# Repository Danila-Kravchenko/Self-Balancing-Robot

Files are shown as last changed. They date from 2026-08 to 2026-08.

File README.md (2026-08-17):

# Балансирующий робот

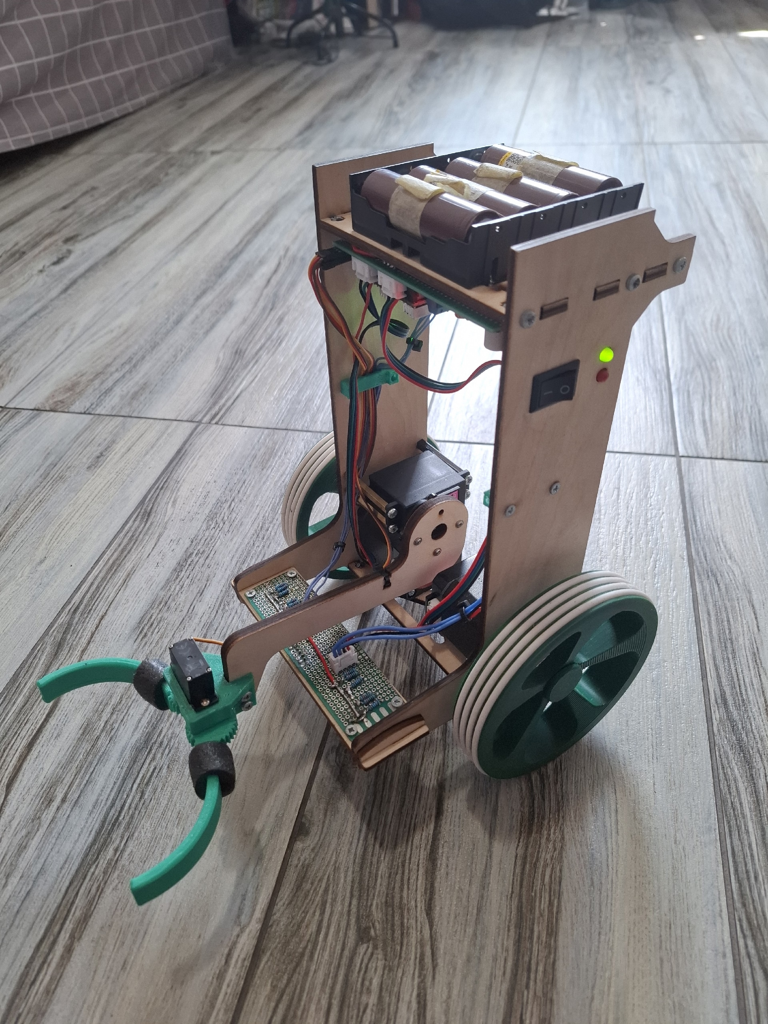
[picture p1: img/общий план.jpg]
общий план


Робот предназначен для выступления на соревнованиях РобоФинист в категории «Гонки балансирующих роботов».
Задача робота — проехать вытянутый S-образный полигон, преодолевая препятствия (горку и кирпич), а также захватить муфту на первом прямолинейном участке.
Победитель определяется по наибольшему числу набранных баллов или по более быстрой попытке.
Подробнее с регламентом можно ознакомиться по [ссылке](https://cdn.robofinist.ru/files/324540/filename/%D0%A0%D0%B5%D0%B3%D0%BB%D0%B0%D0%BC%D0%B5%D0%BD%D1%82%20%D0%93%D0%BE%D0%BD%D0%BA%D0%B8%20%D0%B1%D0%B0%D0%BB%D0%B0%D0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).

---

## Аппаратная архитектура

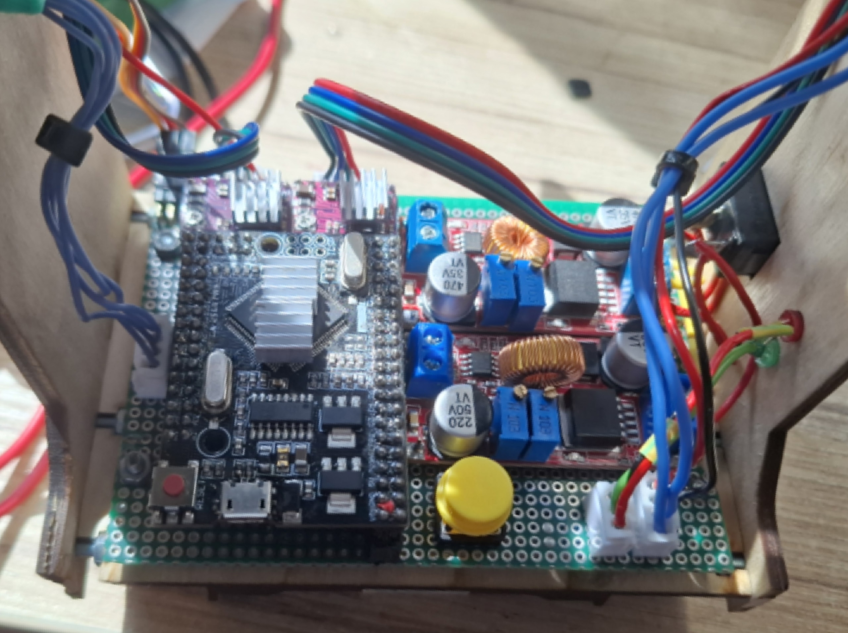
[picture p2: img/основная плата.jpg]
основная плата


### Контроллер
* Arduino Mega 2560 Pro.

### Датчики и сенсоры
* **Удержание угла:** инерциальный модуль BNO-055.
* **Интерфейс:** тактовая кнопка для калибровки систем и старта алгоритма.
* **Следование по линии:** 4 оптопары TCRT5000.
* **Обнаружение препятствий:** лазерный дальномер VL53L1X.

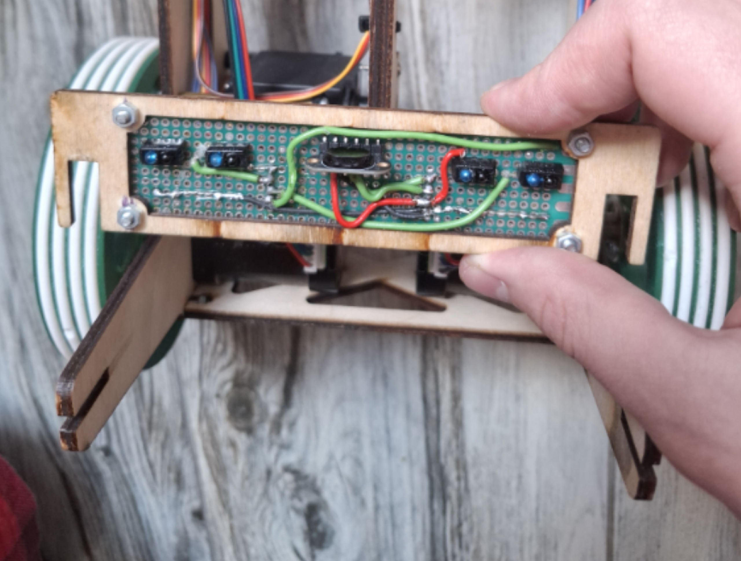
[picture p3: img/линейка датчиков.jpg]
линейка датчиков


### Исполнительные устройства
* **Моторы:** 2 шаговых двигателя Nema 17 17HS8401.
* **Драйверы управления двигателями:** DRV8825.
* **Манипулятор:**
    * сервопривод подъёма стрелы — MG996R;
    * сервопривод клешней — Kingmax KM0940MD.

### Система питания
* **Источник питания:** сборка 4S1P из Li-ion аккумуляторов 18650, 3000 мА·ч.
* **Распределение питания:**
    * шаговые двигатели — 16 В (напрямую от батареи);
    * сервоприводы — 7 В от стабилизатора XL4015;
    * контроллер — 6 В от второго стабилизатора XL4015 на пин Vin;
    * сенсоры — 5 В от пина 5V контроллера.

---

## Конструкция и механика

* **Рама:** лазерная резка из фанеры 4 мм. Сборка выполнена по системе «шип-паз» с механической фиксацией винтами.
* **Фронтальный модуль сенсоров:** дальномер и линейка датчиков линии объединены на единой съёмной текстолитовой плате в передней части робота.
* **Кабель-менеджмент:** по бортам робота установлены напечатанные на 3D-принтере фиксирующие гребёнки для укладки проводов.
* **Движители:** кастомные колёса (3D-печать). В пазы колёс установлены силиконовые шнуры диаметром 3 мм, склеенные в кольца суперклеем.

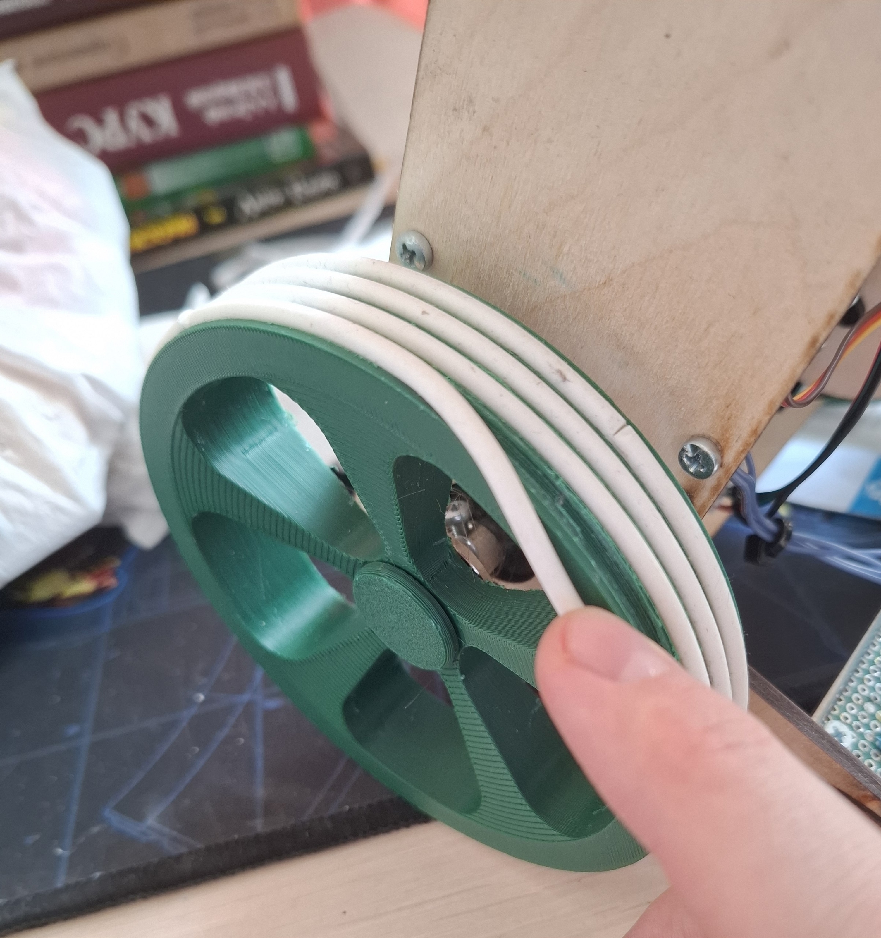
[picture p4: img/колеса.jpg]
колеса


* **Рабочий орган:** клешни манипулятора спроектированы под геометрию муфты и распечатаны на 3D-принтере.

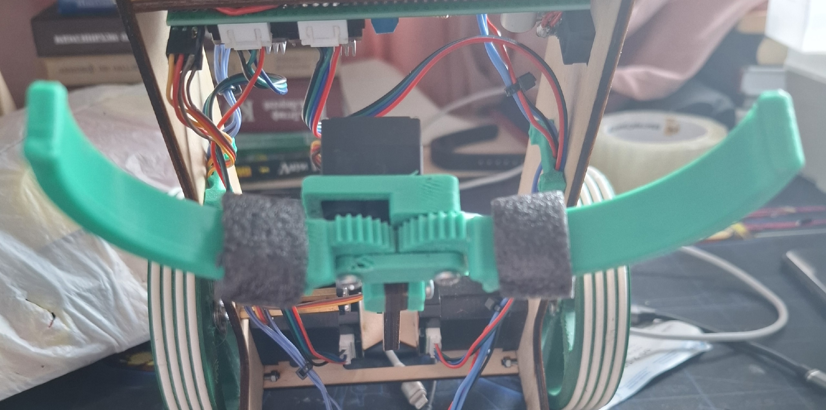
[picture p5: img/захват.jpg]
захват


---

## Алгоритмы и логика управления

### Удержание положения
* **Защита от пропуска шагов ШД:** реализована функция плавного разгона до заданной скорости.
* **Удержание угла:** ПИД-регулятор на основе показаний инерциального модуля.

### Управление перемещением
* **Линейная скорость:** ПИ-регулятор:
    * **текущие показания:** линейная скорость средней точки робота;
    * **фильтрация:** фильтр низких частот для показаний скорости;
    * **управляющее воздействие:** подаётся на регулятор угла.
* **Перемещение по линии:** П-регулятор:
    * **пересчёт ошибки:** взвешенная сумма показаний датчиков отражения света.

---

## Структура ПО
* `self_balancing_robot.ino` — главный файл;
* `IMU.ino` — работа с инерциальным модулем;
* `LED.ino` — управление светодиодами;
* `VL53L1X.ino` — работа с лазерным дальномером;
* `balance.ino` — балансировка и перемещение с заданной скоростью;
* `motors.ino` — управление моторами;
* `move.ino` — выполнение основной задачи (прохождение трассы);
* `servo.ino` — управление сервоприводами.

---

## Сборка и запуск

### Комплектующие и материалы

**Электронные комплектующие**

| Группа | Наименование | Модель / номинал | Кол-во | Назначение |
|---|---|---|:---:|---|
| Контроллер | Микроконтроллер | Arduino Mega 2560 Pro | 1 | Главное вычислительное ядро |
| Сенсоры | Инерциальный модуль | BNO-055 | 1 | Удержание угла |
| Сенсоры | Лазерный дальномер | VL53L1X | 1 | Обнаружение препятствий |
| Сенсоры | Оптопара | TCRT5000 | 4 | Следование по линии |
| Приводы | Шаговый двигатель | Nema 17 17HS8401 | 2 | Движение и балансировка |
| Приводы | Драйвер ШД | DRV8825 | 2 | Управление фазами ШД |
| Приводы | Сервопривод | MG996R | 1 | Подъём стрелы манипулятора |
| Приводы | Сервопривод | Kingmax KM0940MD | 1 | Клешни захвата |
| Питание | Аккумулятор | Li-ion 18650, 3000 мА·ч | 4 | Сборка 4S1P |
| Питание | Холдер аккумуляторов | 4 × 18650 | 1 | Монтаж и коммутация АКБ |
| Питание | DC-DC преобразователь | XL4015 | 2 | Шины 7 В и 6 В |
| Питание | Тумблер | — | 1 | Коммутация питания |
| Обвязка | Конденсатор электролитический | 100 мкФ, 25 В | 2 | Сглаживание пульсаций по питанию драйверов |
| Обвязка | Резистор | 220 Ом | 2 | Токоограничение светодиодов |
| Обвязка | Резистор | 1 кОм | 5 | Обвязка сенсоров, делитель напряжения |
| Обвязка | Светодиод | 5 мм | 2 | Индикация батареи и состояния |
| Обвязка | Кнопка тактовая | 6 × 6 мм | 1 | Калибровка и старт |
| Монтаж | Плата макетная паячная | 9 × 15 см | 1 | Монтаж электроники |

**Механические комплектующие и материалы**

| Группа | Наименование | Характеристики | Кол-во | Назначение |
|---|---|---|:---:|---|
| Рама | Фанера берёзовая | 4 мм | — | Несущие панели рамы (лазерная резка) |
| Рама | Фанера берёзовая | 3 мм | — | Вспомогательные детали |
| 3D-печать | Пластик для 3D-печати | ABS / PETG / PLA | — | Колёса, клешни, гребёнки, кронштейны |
| Кинематика | Муфта соединительная | под ось 5 мм | 2 | Сопряжение вала ШД с колесом |
| Кинематика | Шнур силиконовый | Ø 3 мм | 3 м | Эластичные шины колёс |
| Крепёж | Винты и гайки | M3 | набор | Механическая фиксация узлов |
| Крепёж | Стойка металлическая | M3 × 40 мм | 4 | Монтаж основных узлов |
| Крепёж | Стойка пластиковая | M3 × 8 мм | 4 | Монтаж плат |
| Расходники | Клей цианоакрилатный (суперклей) | — | 1 | Склеивание силиконовых колец |
| Расходники | Стяжка нейлоновая | — | набор | Кабель-менеджмент |

### Необходимое ПО
* Arduino IDE 2.0;
* библиотеки (устанавливаются через менеджер библиотек):
    * [VL53L1X](https://github.com/pololu/vl53l1x-arduino.git);
    * [TimerOne](https://github.com/PaulStoffregen/TimerOne.git);
    * [TimerThree](https://github.com/PaulStoffregen/TimerThree.git).
* Скетч находится в папке `firmware/balancing_robot/`.

### Подключение

| Пин Arduino | Тип | Назначение | Примечание |
|---|-----|---|---|
| 4 | Цифровой | `MOTOR_DIR_L` — направление левого ШД | |
| 5 | Цифровой | `MOTOR_STEP_L` — шаг левого ШД | Аппаратный таймер Timer3 |
| 9 | PWM | `CLAWS_PIN` — сервопривод клешней | |
| 10 | PWM | `ARM_PIN` — сервопривод подъёма стрелы | |
| 11 | Цифровой | `MOTOR_STEP_R` — шаг правого ШД | Аппаратный таймер Timer1 |
| 12 | Цифровой | `MOTOR_DIR_R` — направление правого ШД | |
| 13 | Цифровой | `BUTTON_PIN` — тактовая кнопка старта | INPUT_PULLUP |
| 15 | Цифровой | `BATTERY_LED_PIN` — индикация батареи | Через резистор 220 Ом |
| 17 | Цифровой | `ACTION_LED_PIN` — индикация состояния | Через резистор 220 Ом |
| 20 (SDA) | I²C | SDA — шина данных BNO-055 и VL53L1X | Стандартные пины Mega |
| 21 (SCL) | I²C | SCL — тактовая линия I²C | |
| A1 | Аналоговый | `SENSORS_PIN[0]` — TCRT5000 (крайний левый) | |
| A3 | Аналоговый | `SENSORS_PIN[1]` — TCRT5000 | |
| A5 | Аналоговый | `SENSORS_PIN[2]` — TCRT5000 | |
| A7 | Аналоговый | `SENSORS_PIN[3]` — TCRT5000 (крайний правый) | |
| A9 | Аналоговый | `VOLTAGE_PIN` — измерение напряжения батареи | Делитель напряжения |

### Порядок запуска
1. **Калибровка датчиков:** при включении робота удерживайте его неподвижно на ровной поверхности, пока BNO-055 выполняет внутреннюю калибровку гироскопа и акселерометра (контролируется по светодиодной индикации или через Serial).
2. **Инициализация:** установите робота в горизонтальное положение — он начнёт удерживать баланс. Поместите робота в стартовую зону.
3. **Старт:** нажмите тактовую кнопку на корпусе для запуска основной программы.

---

## Демонстрация
* Видео с демонстрацией работы расположено в папке `demo/`.

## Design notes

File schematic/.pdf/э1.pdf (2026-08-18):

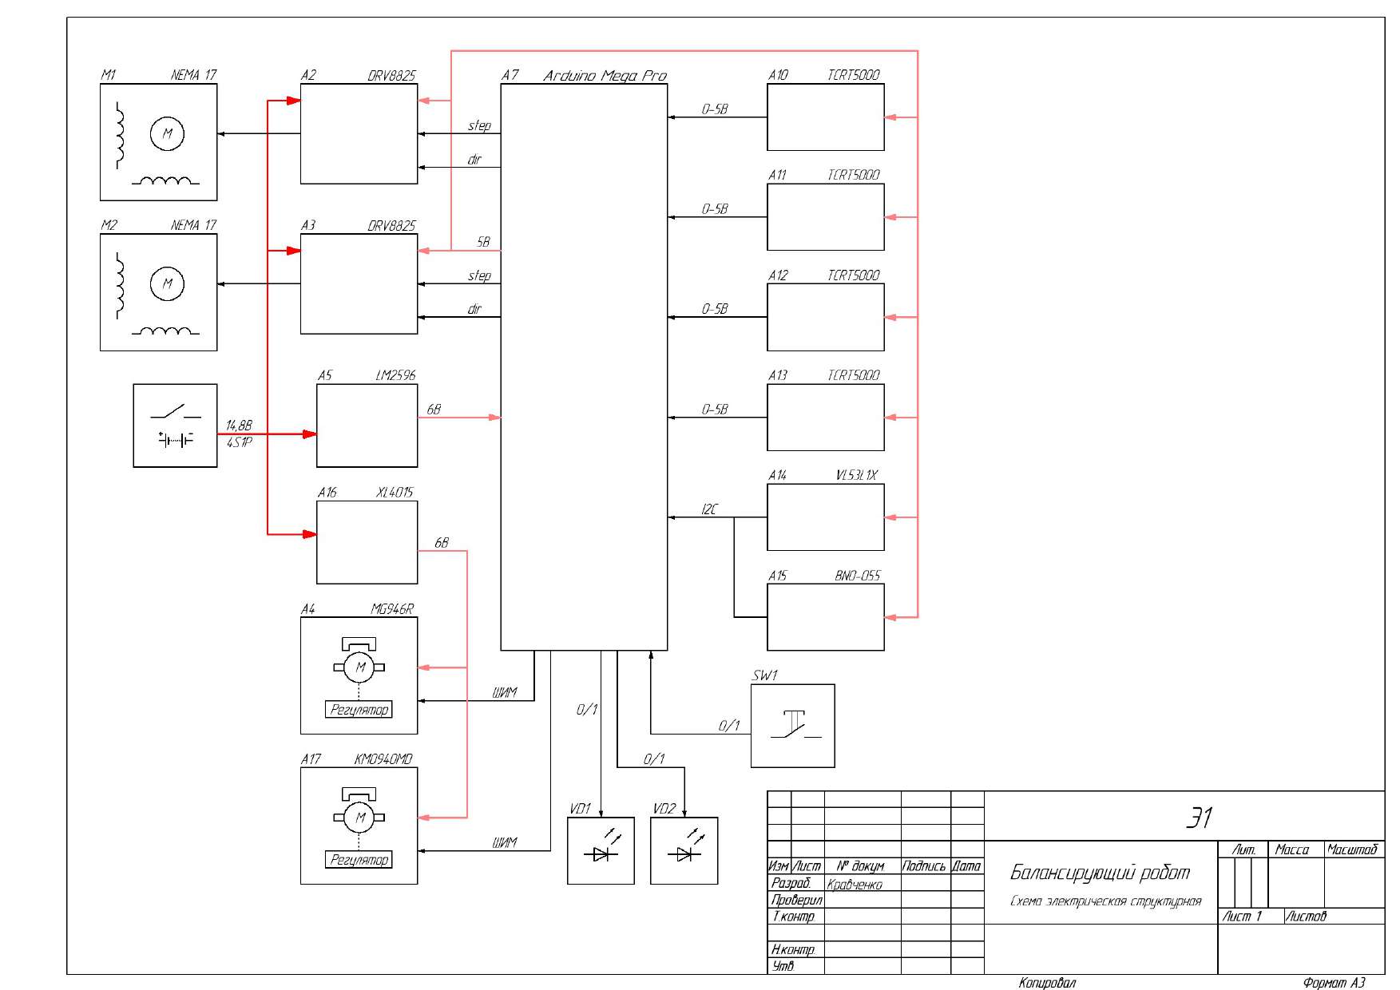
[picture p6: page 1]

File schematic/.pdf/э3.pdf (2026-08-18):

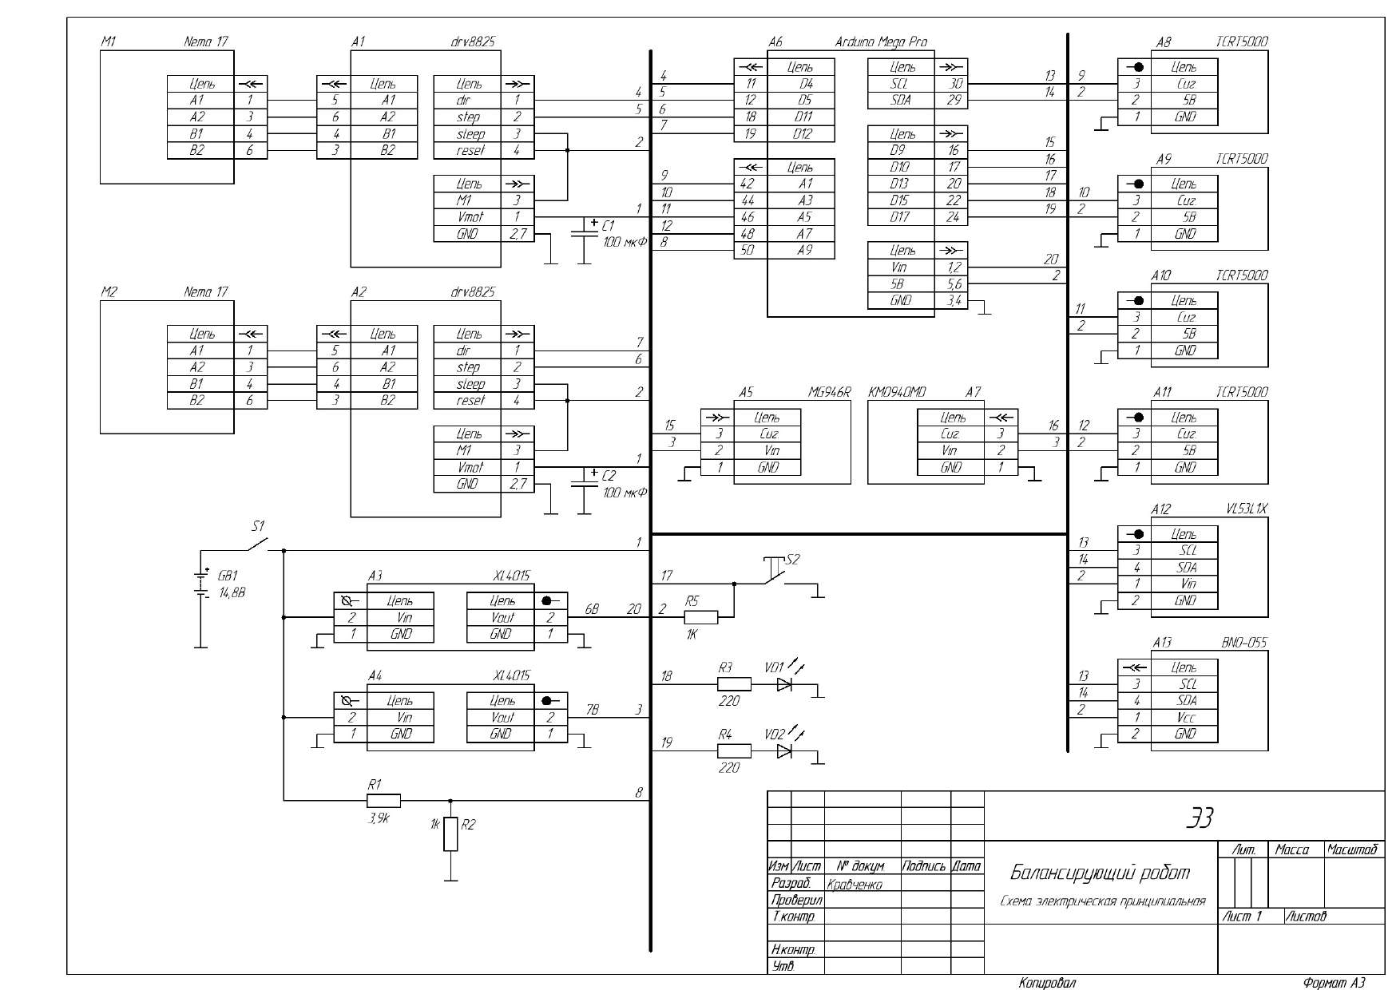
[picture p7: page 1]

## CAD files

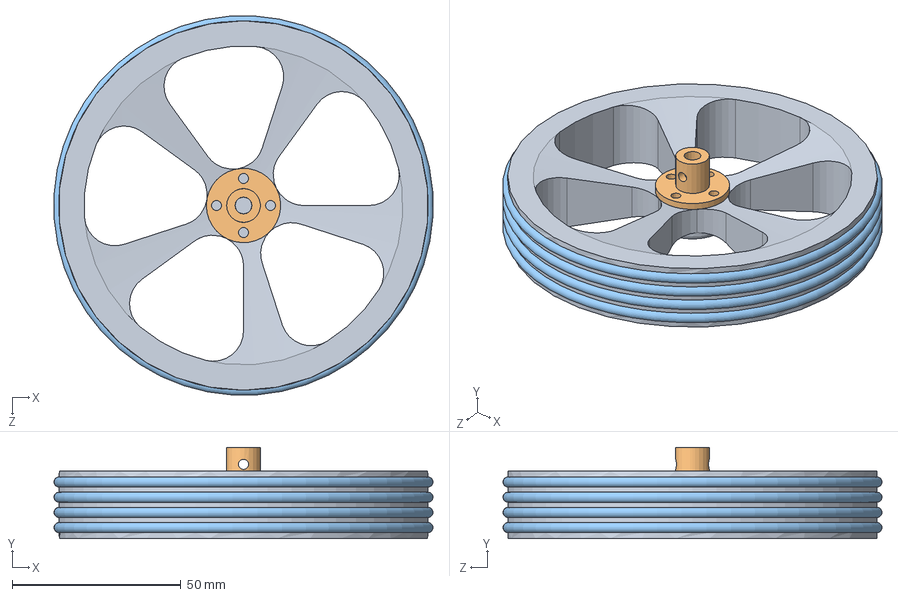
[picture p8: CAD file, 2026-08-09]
mechanics/3d model/колесо.SLDASM
112.2 x 27.0 x 112.2 mm
колесо
втулка
резинка x 4

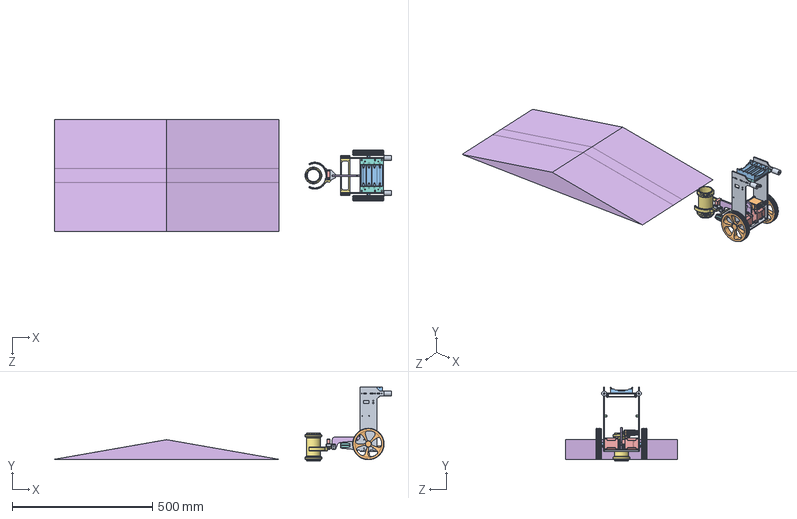
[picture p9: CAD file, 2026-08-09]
mechanics/3d model/балансир.SLDASM
1202.1 x 263.5 x 400.0 mm
боковинка x 2
колесо x 2
втулка x 2
резинка x 8
motor_17hs8401 x 2
горка
основание под линейку датчиков
защелка основания x 2
основание
MG996R
18650 Cell Holder
стойка под серву x 4
MG995_Gear2
рычаг манипулятора
муфта
платформа под аккумуляторный отсек
поролоновая труба x 2
стойки для платы x 4
плата
гребенка для кабелей x 2
kmo940md
servo horn
клешня x 2
соединитель клешней
Деталь1

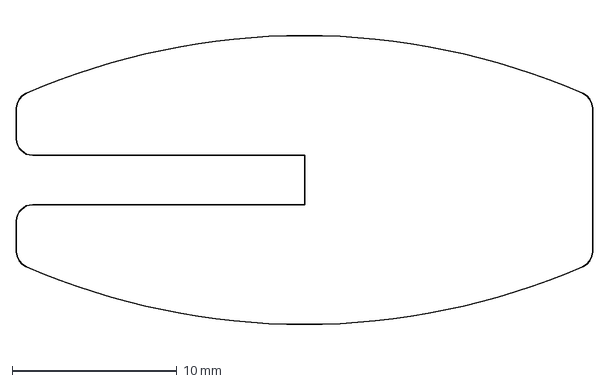
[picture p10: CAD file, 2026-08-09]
mechanics/.dxf/3 mm/защелка основания.DXF
35.0 x 19.9 mm

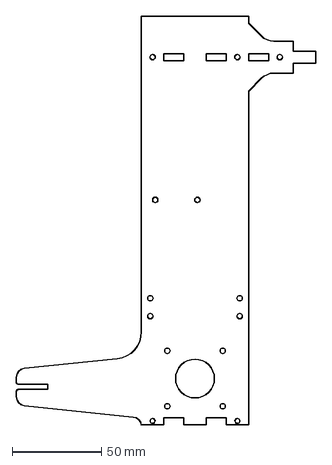
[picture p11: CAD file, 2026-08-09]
mechanics/.dxf/4 mm/правая боковинка.DXF
167.5 x 229.0 mm

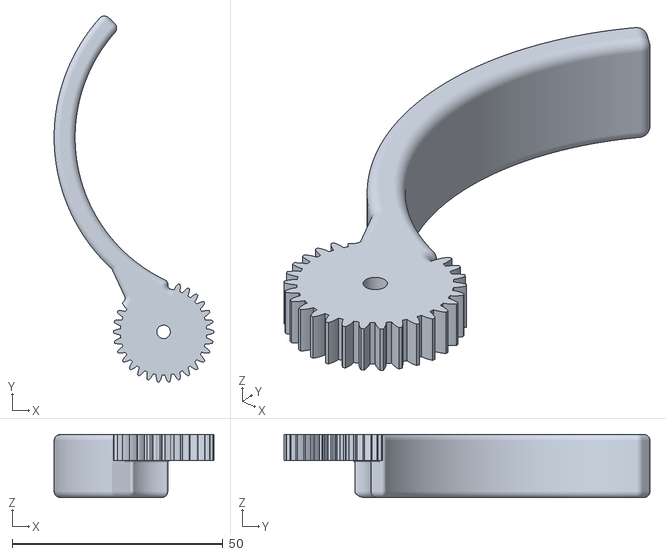
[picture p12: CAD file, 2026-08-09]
mechanics/.stl/левая клешня.STL
37.9 x 86.9 x 15.0

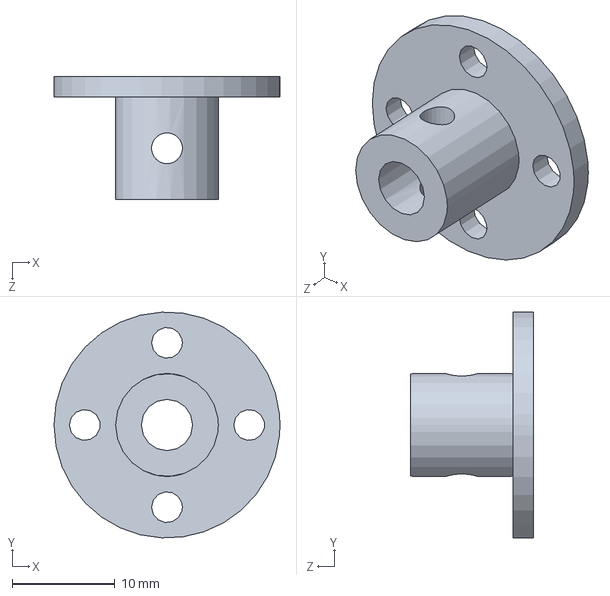
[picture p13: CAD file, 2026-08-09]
mechanics/3d model/втулка.SLDPRT
22.0 x 22.0 x 12.0 mm

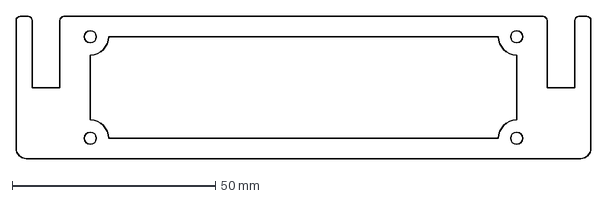
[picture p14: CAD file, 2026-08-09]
mechanics/.dxf/3 mm/основание под линейку датчиков.DXF
141.6 x 35.0 mm

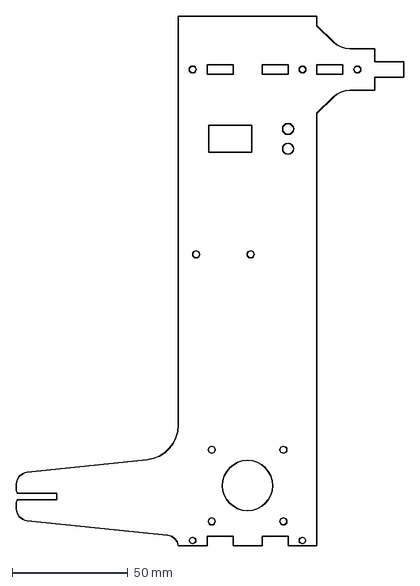
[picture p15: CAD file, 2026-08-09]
mechanics/.dxf/4 mm/левая боковинка.DXF
167.5 x 229.0 mm

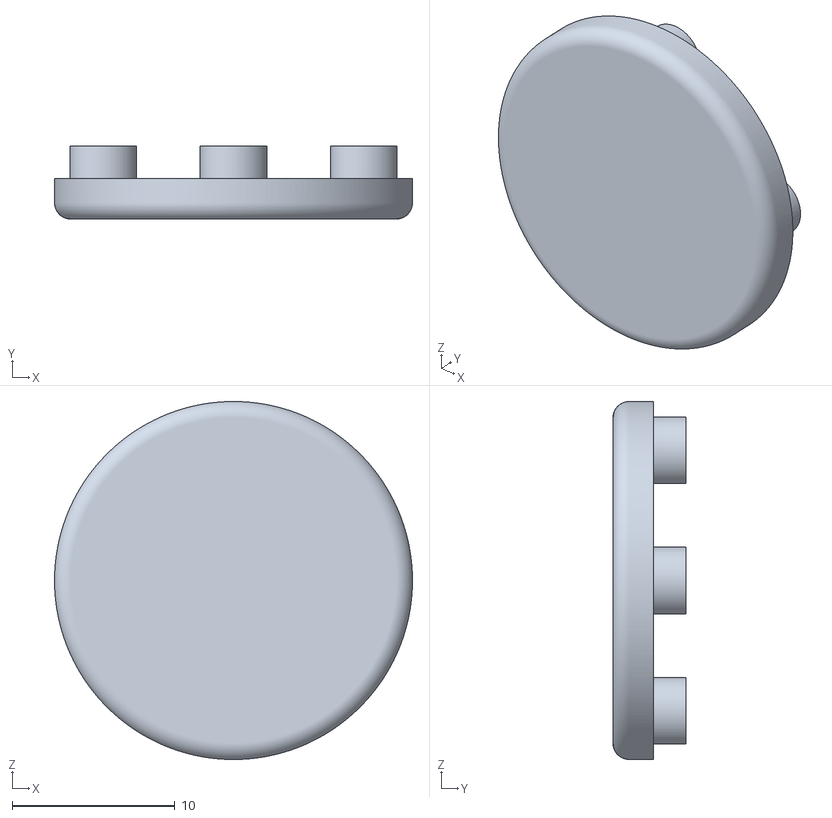
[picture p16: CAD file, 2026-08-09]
mechanics/.stl/заглушка.STL
22.0 x 4.50 x 22.0

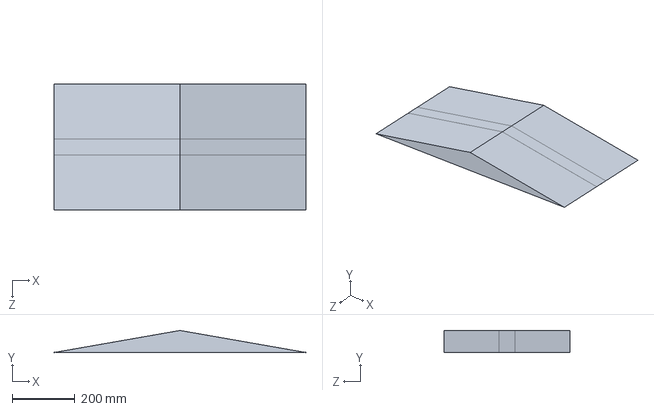
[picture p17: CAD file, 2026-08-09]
mechanics/3d model/горка.SLDPRT
800.0 x 70.1 x 400.0 mm

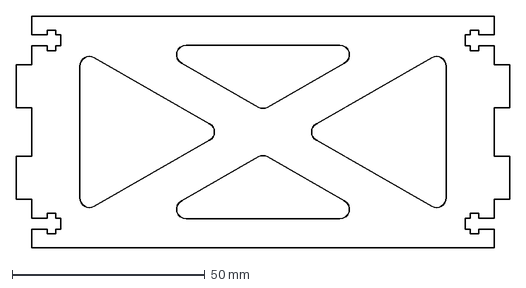
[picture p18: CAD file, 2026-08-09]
mechanics/.dxf/4 mm/основание.DXF
128.0 x 60.0 mm

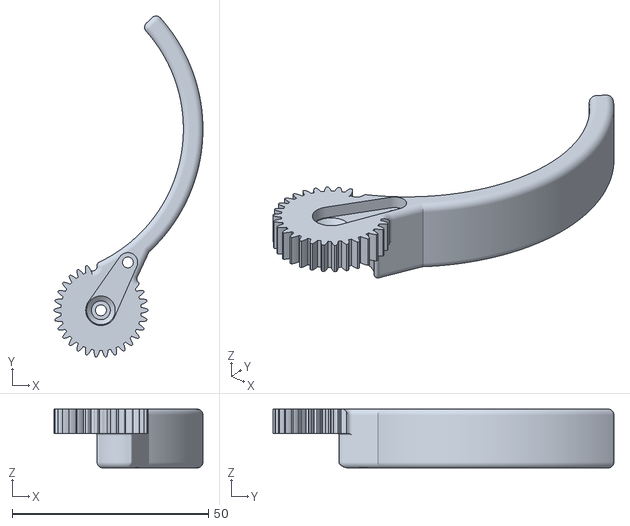
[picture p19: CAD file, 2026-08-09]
mechanics/.stl/правая клешня.STL
37.9 x 86.9 x 15.0

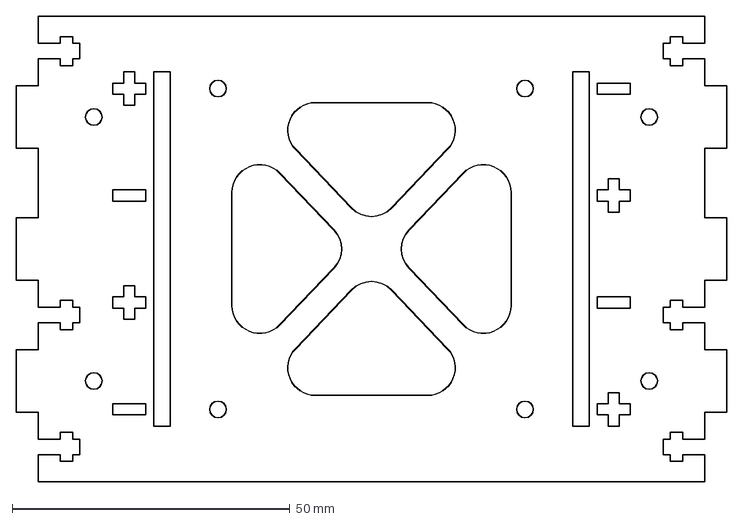
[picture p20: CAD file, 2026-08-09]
mechanics/.dxf/4 mm/платформа под аккумуляторный отсек.DXF
128.0 x 83.8 mm

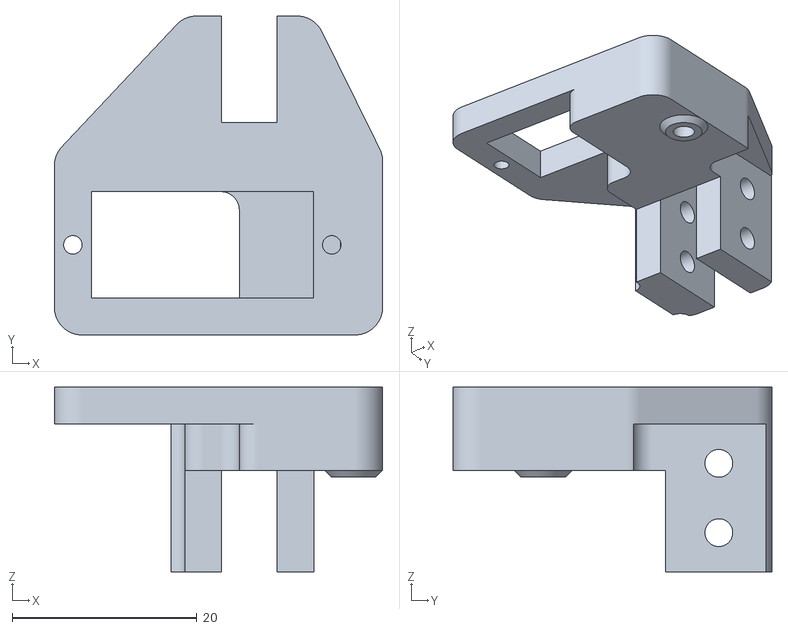
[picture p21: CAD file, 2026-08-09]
mechanics/.stl/основа захвата.STL
35.5 x 34.5 x 20.0

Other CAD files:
mechanics/3d model/платформа под аккумуляторный отсек.SLDPRT
mechanics/3d model/MG995_Gear2.SLDPRT
mechanics/3d model/платформа захвата.SLDPRT
mechanics/3d model/поролоновая труба.SLDPRT
mechanics/.stl/гребенка для кабелей.STL
mechanics/.stl/соединитель клешней.STL
mechanics/3d model/18650 Cell Holder.SLDPRT
mechanics/3d model/LED 5 mm.SLDPRT
mechanics/3d model/MG996R.SLDPRT
mechanics/3d model/kmo940md.SLDPRT
mechanics/3d model/motor_17hs8401.SLDPRT
mechanics/3d model/servo horn.SLDPRT
mechanics/3d model/Деталь1.SLDPRT
mechanics/3d model/боковинка.SLDPRT
mechanics/3d model/гребенка для кабелей.SLDPRT
mechanics/3d model/защелка основания.SLDPRT
mechanics/3d model/клешня.SLDPRT
mechanics/3d model/колесо.SLDPRT
mechanics/3d model/кронштейн для левой клешни.SLDPRT
mechanics/3d model/муфта.SLDPRT
mechanics/3d model/опоры.SLDPRT
mechanics/3d model/основание под линейку датчиков.SLDPRT
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

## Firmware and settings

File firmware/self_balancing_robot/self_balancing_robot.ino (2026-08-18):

#define SERIAL_SPEED 115200
#define Ts 10
#define Ts_s (Ts / 1000.0)

extern void wait(double ms = Ts);
extern double angles[3];

void setup() {
  Serial.begin(SERIAL_SPEED);
  init_button();
  while (!button_pressed())
    ;

  init_led();

  if (check_battery() <= 14) {
    Serial.println("low battery");
    while (1)
      ;
  }

  init_wire();
  init_vl53l1x();
  init_bno();
  init_motors();
  init_servo();
  light(1);
  Serial.println("ready");

  // Установка робота в вертикальное положение
  delay(500);
  update_angle();
  wait();
  while (abs(angles[0]) > 0.5) {
    update_angle();
    wait();
    Serial.println(angles[0]);
  }

  // Основной алгоритм перемещения
  wait_start();
  main_task();
}

void loop() {
  static uint32_t timer = millis();
  
  while (millis() - timer < 250) set_angle(0);
  motor(0, 0);
}

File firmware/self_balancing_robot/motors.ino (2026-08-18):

#include <TimerOne.h>
#include <TimerThree.h>

#define MOTOR_STEP_L 5
#define MOTOR_DIR_L 4
#define MOTOR_STEP_R 11
#define MOTOR_DIR_R 12

#define RADIUS 350.0 / PI / 2
#define STEPS_PER_ROTATE 200.0
#define DIST_PER_TICK 2 * PI* RADIUS / STEPS_PER_ROTATE
#define STEP_RESOLUTION 16

#define ACCEL 17500 //25000
#define V_MAX 1100.0

volatile int stepL = 0, stepR = 0;
int dirL = 1, dirR = 1, distL, distR, center;
double spd = 0;

void init_motors() {
  pinMode(MOTOR_DIR_L, OUTPUT);
  pinMode(MOTOR_STEP_L, OUTPUT);
  pinMode(MOTOR_DIR_R, OUTPUT);
  pinMode(MOTOR_STEP_R, OUTPUT);

  Timer1.initialize(1000);
  Timer1.attachInterrupt(ISR_L);
  Timer1.stop();

  Timer3.initialize(1000);
  Timer3.attachInterrupt(ISR_R);
  Timer3.stop();
}

// Используются прерывания по аппартным таймерам
void ISR_L() {
  static bool step_state_L = false;

  digitalWrite(MOTOR_STEP_L, step_state_L);
  digitalWrite(MOTOR_DIR_L, dirL == 1 ? 0 : 1);

  stepL += dirL * step_state_L;

  step_state_L = 1 - step_state_L;
}
void ISR_R() {
  static bool step_state_R = false;

  digitalWrite(MOTOR_STEP_R, step_state_R);
  digitalWrite(MOTOR_DIR_R, dirR == 1 ? 1 : 0);

  stepR += dirR * step_state_R;

  step_state_R = 1 - step_state_R;
}
void count_dist(){
  distL = stepL * DIST_PER_TICK / STEP_RESOLUTION;
  distR = stepR * DIST_PER_TICK / STEP_RESOLUTION;
  center = (distL + distR) / 2;
}

void dist_to_zero() {
  stepL = 0, stepR = 0;
  count_dist();
}

// Увеличение параметра с заданным ускорением
double acceleration(double V_curr, double V_wish, double accel = ACCEL) {
  static double err;
  err = V_wish - V_curr;
  return min(accel * Ts / 1000, abs(err)) * sign(err);
}
int sign(double input) {
  return (input >= 0) ? 1 : -1;
}

void motor(double speedL, double speedR) {
  static double speed_x_last = 0, speed_y_last = 0;
  static double speedL_curr = 0, speedR_curr = 0, periodL = 1, periodR = 1, last_periodL = 1, last_periodR = 1;

  speedL = constrain(speedL, -V_MAX, V_MAX);
  speedR = constrain(speedR, -V_MAX, V_MAX);
  speedL_curr += acceleration(speedL_curr, speedL);
  speedR_curr += acceleration(speedR_curr, speedR);

  static double k_speed = 0.895;
  spd = spd * k_speed + (1 - k_speed) * (speedL_curr + speedR_curr) / 2;

  if (abs(speedL_curr) >= DIST_PER_TICK / STEP_RESOLUTION) {
    dirL = (speedL_curr > 0) ? 1 : -1;

    speedL = abs(speedL_curr);
    periodL = 1000000 * DIST_PER_TICK / speedL / 2 / STEP_RESOLUTION;

    if (last_periodL != periodL) {
      Timer1.setPeriod(periodL);
      Timer1.start();
    }
  } else {
    Timer1.stop();
  }
  last_periodL = periodL;

  if (abs(speedR_curr) >= DIST_PER_TICK / STEP_RESOLUTION) {
    dirR = (speedR_curr > 0) ? 1 : -1;

    speedR = abs(speedR_curr);
    periodR = 1000000 * DIST_PER_TICK / speedR / 2 / STEP_RESOLUTION;

    if (last_periodR != periodR) {
      Timer3.setPeriod(periodR);
      Timer3.start();
    }
  } else {
    Timer3.stop();
  }
  last_periodR = periodR;
}

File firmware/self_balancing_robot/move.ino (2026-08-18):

#define BUTTON_PIN 13
#define BLACK_TRESHOLD 425
const int SENSORS_PIN[] = { A1, A3, A5, A7 };
const double LINE_SENS_FACTOR[] = { -1.5, -1.3, 1, 1.5 };
bool is_black[4];
int amounts_of_black = 0;

extern double rot_comp;

void init_button() {
  pinMode(BUTTON_PIN, INPUT);
}
bool button_pressed() {
  return (1 - digitalRead(BUTTON_PIN));
}
void wait_start() {
  while (!button_pressed()) {
    down();
    open_claws();
    speed(0);
  }
}

void show_line_sens_data(bool print_end = false) {
  for (int sensor = 0; sensor < 4; sensor++) {
    Serial.print(analogRead(SENSORS_PIN[sensor]) * LINE_SENS_FACTOR[sensor]);
    Serial.print("\t");
  }
  if (print_end) Serial.println();
}
int count_err() {
  static int err;

  err = 0;
  for (int sensor = 0; sensor < 4; sensor++) {
    err += analogRead(SENSORS_PIN[sensor]) * LINE_SENS_FACTOR[sensor];
  }
  return err;
}
void check_black() {
  amounts_of_black = 0;
  for (int sensor = 0; sensor < 4; sensor++) {
    if (analogRead(SENSORS_PIN[sensor]) >= BLACK_TRESHOLD) {
      is_black[sensor] = true;
      amounts_of_black++;
    } else {
      is_black[sensor] = false;
    }
  }
}

void line(int wish_speed) {
  static int err, u;
  static double k = 0.2;

  err = count_err();
  u = err * k;
  rot_comp = u;
  speed(wish_speed);
}
void line_by_dist(int wish_speed, int dist) {
  dist_to_zero();
  while (center < dist) line(wish_speed);
}
void line_by_time(int wish_speed, int wish_time) {
  static uint32_t timer;

  timer = millis();
  while (millis() - timer < wish_time) line(wish_speed);
}
void line_by_angle(int wish_speed, int wish_angle) {
  z_to_zero();

  while (abs(angles[2]) < abs(wish_angle)) line(wish_speed);
}
void line_to_cross(int wish_speed){
  while (amounts_of_black < 3) line(wish_speed);
}

// Основной код выполненияя задания
void main_task() {
  //муфта
  line_by_dist(500, 800);
  close_claws();
  line_by_time(500, 100);
  up();
  line_by_angle(500, 175);
  light(0);

  //объезд
  line_by_dist(500, 200);
  light(1);
  z_to_zero();
  while (abs(angles[2]) < 5) {
    rot_comp = -100;
    speed(500);
  }
  while (abs(angles[2]) < 20) {
    rot_comp = -250;
    speed(500);
  }
  dist_to_zero();
  while (center < 275) {
    speed(500);
  }
  z_to_zero();
  while (abs(angles[2]) < 50) {
    rot_comp = 175;
    speed(500);
  }
  dist_to_zero();
  while (center < 275) {
    speed(500);
  }
  z_to_zero();
  while (abs(angles[2]) < 20) {
    rot_comp = -125;
    speed(500);
  }
  light(0);
  line_by_dist(500, 50);

  line_by_angle(500, 170);

  //горка
  line_by_dist(500, 400);
  light(1);
  //line_by_dist(300, 800);
  line_by_time(300, 2600);
  down();
}
